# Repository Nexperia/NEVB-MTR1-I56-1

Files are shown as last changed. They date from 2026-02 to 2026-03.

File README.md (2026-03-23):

<picture align="center">
  <source media="(prefers-color-scheme: dark)" srcset="https://raw.githubusercontent.com/Nexperia/NEVB-MTR1-I56-1/refs/heads/main/images/nexperia_logo_white.svg">
  Nexperia Logo
</picture>

-----------------
# NEVB-MTR1-I56-1: 3-Phase Inverter Board Hardware Design Files

 

## Introduction

This repository contains the hardware design files for the NEVB-MTR1-I56-1 3-Phase Inverter Board, a key component of Nexperia's Motor Evaluation Kit NEVB-MTR1-KIT1. The inverter board serves as the main powerstage for driving the motor, interfacing with the Motor Controller Board.

The NEVB-MTR1-KIT1 evaluation kit includes:

- **Motor Controller Board (NEVB-MTR1-C-1)**: The central unit for motor control operations.
- **3-Phase Inverter Board (NEVB-MTR1-I56-1)**: The main powerstage for driving the motor (this repository).
- **Leonardo R3 Development Board**: Acts as the core microcontroller platform for the system.
- **3-Phase BLDC Motor with Hall Sensors**: The motor that is directly controlled by the system.
- Additional screws, plugs, and tools necessary for setup and operation.

## Board View

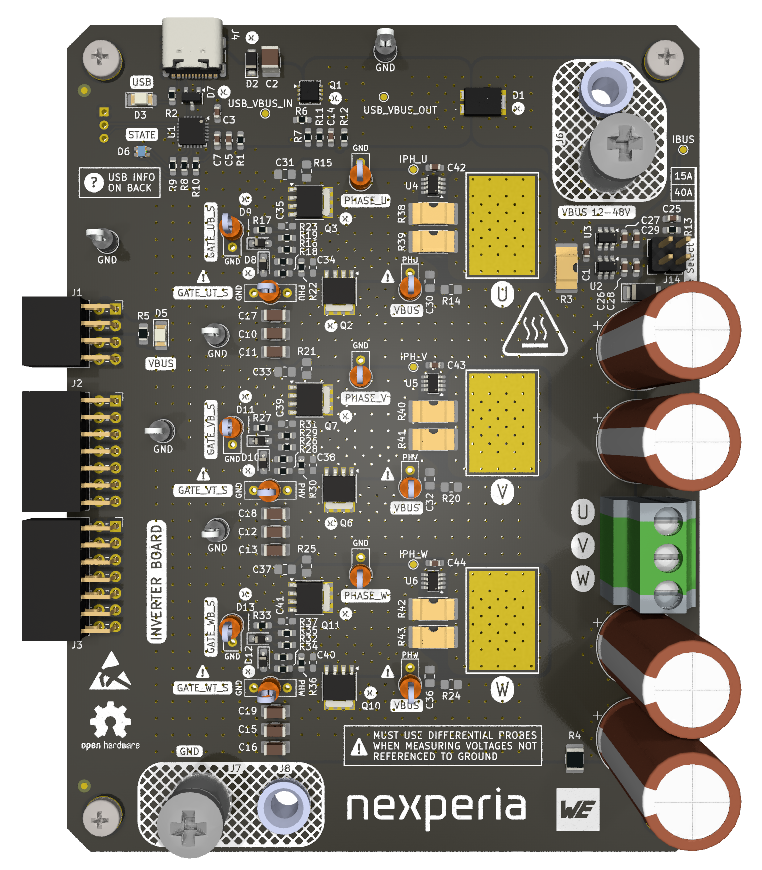
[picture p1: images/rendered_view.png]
Board Render


## Bill of Materials

An interactive Bill of Materials (iBOM) is available online at [https://nexperia.github.io/NEVB-MTR1-I56-1/ibom.html](https://nexperia.github.io/NEVB-MTR1-I56-1/ibom.html) or locally in the `bom/` directory (`bom/ibom.html`). The iBOM provides an interactive view of component placement, reference designators, and sourcing information. The BOM is also available in CSV format at `bom/nevb_mtr1_i56_1.csv`.

## Manufacturing Files

Gerber files for PCB manufacturing are located in the `gerbers/` directory.

## Design Software

This board was designed using [KiCad](https://www.kicad.org/) EDA software (version 9.0 or newer recommended).

To open and edit the design:

1. Install KiCad from [https://www.kicad.org/download/](https://www.kicad.org/download/)
2. Open the project file: `nevb_mtr1_i56_1.kicad_pro`

## Related Repositories

- **Firmware**: [NEVC-MTR1-t01](https://github.com/Nexperia/NEVC-MTR1-t01) - Trapezoidal control firmware for the evaluation kit
- **Motor Controller Board** [NEVB-MTR1-C-1](https://github.com/Nexperia/NEVB-MTR1-C-1) - Design files for the motor controller board

## Safety Precautions

When working with these hardware designs, exercise caution with high-voltage components and follow proper ESD, assembly, and testing procedures.

## Contributing

Contributions to improve the hardware design are welcome. To contribute:

- Fork the repository.
- Create a new branch for your feature or fix.
- Commit your changes with clear documentation.
- Push to your branch and submit a pull request.

## License

This project is licensed under the MIT/X Consortium License, a permissive free software license. For more details on the MIT/X Consortium License, please refer to the LICENSE file included in this repository.

## Schematics

The inverter board design is organized into hierarchical schematic sheets:

Main Schematic

Power Input

Input Current Sense

Capacitor Bank

Inverter

Phase Current Sense

Hardware and Notes

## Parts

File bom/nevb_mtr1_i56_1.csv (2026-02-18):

Reference | Value | Datasheet | Footprint | Qty | DNP | Manufacturer | Mfg Part No | Mouser Part No | RS Part No | Farnell Part No
C1 | 10n-100V | https://www.we-online.com/components/products/datasheet/885012206114.pdf | Capacitor_SMD:C_0603_1608Metric_Pad1.08x0.95mm_HandSolder | 1 |  | WURTH ELEKTRONIK | 885012206114 | 710-885012206114 | ~ | 2812368
C2 | 4.7u-25V | https://www.we-online.com/components/products/datasheet/885012209027.pdf | Capacitor_SMD:C_1210_3225Metric_Pad1.33x2.70mm_HandSolder | 1 |  | WURTH ELEKTRONIK | 885012209027 | 710-885012209027 | ~ | 4261488
C3,C14 | 0.1u-25V | https://www.we-online.com/components/products/datasheet/885012206071.pdf | Capacitor_SMD:C_0603_1608Metric_Pad1.08x0.95mm_HandSolder | 2 |  | WURTH ELEKTRONIK | 885012206071 | 710-885012206071 | ~ | 2495173
C4,C6,C8,C9 | 270u-100V | https://www.chemi-con.co.jp/products/relatedfiles/capacitor/catalog/KYBLL-e.PDF | Capacitor_THT:CP_Radial_D12.5mm_P5.00mm | 4 |  | CHEMI-CON | EKYB101ELL271MK30S | 661-EKYB101E271MK30S | ~ | ~
C5,C7 | 1u-6V3 | https://www.we-online.com/components/products/datasheet/885012206002.pdf | Capacitor_SMD:C_0603_1608Metric_Pad1.08x0.95mm_HandSolder | 2 |  | WURTH ELEKTRONIK | 885012206002 | 710-885012206002 | ~ | 2534013
C10,C11,C12,C13,C15,C16 | 4.7u-100V | https://search.murata.co.jp/Ceramy/image/img/A01X/G101/ENG/GRM31CZ72A475KE11-01A.pdf | Capacitor_SMD:C_1206_3216Metric_Pad1.33x1.80mm_HandSolder | 6 |  | MURATA | GRM31CZ72A475KE11L | 81-GRM31CZ72A475K11L | ~ | 4128569
C17,C18,C19 | 1u-100V | https://weblib.samsungsem.com/mlcc/mlcc-ec-data-sheet.do?partNumber=CL31B105KCHSNN | Capacitor_SMD:C_1206_3216Metric_Pad1.33x1.80mm_HandSolder | 3 |  | SAMSUNG ELECTRO-MECHANICS | CL31B105KCHSNNE | 187-CL31B105KCHSNNE | ~ | 4539191
C20,C21,C22,C23,C24 | NC | ~ | Capacitor_SMD:C_2220_5750Metric_Pad1.97x5.40mm_HandSolder | 5 | DNP | ~ | ~ | ~ | ~ | ~
C25 | 22p-16V | https://www.we-online.com/components/products/datasheet/885012006019.pdf | Capacitor_SMD:C_0603_1608Metric_Pad1.08x0.95mm_HandSolder | 1 |  | WURTH ELEKTRONIK | 885012006019 | 710-885012006019 | ~ | 2533830
C26,C27,C42,C43,C44 | 0.1u-16V | https://www.we-online.com/components/products/datasheet/885012206046.pdf | Capacitor_SMD:C_0603_1608Metric_Pad1.08x0.95mm_HandSolder | 5 |  | WURTH ELEKTRONIK | 885012206046 | 710-885012206046 | ~ | 2495170
C28,C29 | 2.2u-16V | https://www.we-online.com/components/products/datasheet/885012106029.pdf | Capacitor_SMD:C_0603_1608Metric_Pad1.08x0.95mm_HandSolder | 2 |  | WURTH ELEKTRONIK | 885012106029 | 710-885012106029 | ~ | 4061671
C30,C31,C32,C33,C36,C37 | NC | ~ | Capacitor_SMD:C_0805_2012Metric_Pad1.18x1.45mm_HandSolder | 6 | DNP | ~ | ~ | ~ | ~ | ~
C34,C35,C38,C39,C40,C41 | NC | ~ | Capacitor_SMD:C_0603_1608Metric_Pad1.08x0.95mm_HandSolder | 6 | DNP | ~ | ~ | ~ | ~ | ~
D1 | PMEG100V080ELPE | https://assets.nexperia.com/documents/data-sheet/PMEG100V080ELPE.pdf | project:CFP15B | 1 |  | NEXPERIA | PMEG100V080ELPEZ | 771-PMEG100V080ELPEZ | ~ | 3934785
D2 | PTVS20VS1UR | https://assets.nexperia.com/documents/data-sheet/PTVSXS1UR_SER.pdf | Diode_SMD:Nexperia_CFP3_SOD-123W | 1 |  | NEXPERIA | PTVS20VS1UR,115 | 771-PTVS20VS1UR115 | ~ | 1829244
D3 | USB | https://www.we-online.com/components/products/datasheet/150120GS75000.pdf | LED_SMD:LED_1206_3216Metric_Pad1.42x1.75mm_HandSolder | 1 |  | WURTH ELEKTRONIK | 150120GS75000 | 710-150120GS75000 | ~ | 2322085
D4 | PTVS60VP1UTP | https://assets.nexperia.com/documents/data-sheet/PTVSXP1UTP_SER.pdf | Diode_SMD:D_SOD-128 | 1 |  | NEXPERIA | PTVS60VP1UTP,115 | 771-PTVS60VP1UTP,115 | ~ | 3940904
D5 | VBUS | https://www.we-online.com/components/products/datasheet/150120GS75000.pdf | LED_SMD:LED_1206_3216Metric_Pad1.42x1.75mm_HandSolder | 1 |  | WURTH ELEKTRONIK | 150120GS75000 | 710-150120GS75000 | ~ | 2322085
D6 | PD STATE | https://www.we-online.com/components/products/datasheet/150066M153000.pdf | project:LED_Wurth_0606 | 1 |  | WURTH ELEKTRONIK | 150066M153000 | 710-150066M153000 | ~ | 2764964
D7 | PESD5V0L2UU | https://assets.nexperia.com/documents/data-sheet/PESD5V0L2UU_PESD6V0L2UU.pdf | Package_TO_SOT_SMD:SOT-23-3 | 1 |  | NEXPERIA | PESD5V0L2UU,115 | 771-PESD5V0L2UU115 | ~ | 2069363
D8,D9,D10,D11,D12,D13 | BAT760 | https://assets.nexperia.com/documents/data-sheet/BAT760.pdf | Diode_SMD:D_SOD-323_HandSoldering | 6 |  | NEXPERIA | BAT760,115 | 771-BAT760-T/R | ~ | 8734593
G1,G3,G7,G9,G13 | M5x6mm Screw | https://docs.rs-online.com/37dd/0900766b814985ee.pdf |  | 5 |  | RS PRO | 908-7693 | ~ | 908-7693 | ~
G2,G6,G8,G12 | M3x8mm Screw | https://docs.rs-online.com/c4c2/A700000009608830.pdf |  | 4 |  | RS PRO | 264-6436 | ~ | 264-6436 | ~
G4,G5,G10,G11 | M3x25mm F/F Standoff | https://www.we-online.com/components/products/datasheet/970250321.pdf |  | 4 |  | WURTH ELEKTRONIK | 970250321 | 710-970250321 | ~ | 2884579
G14 | 2.54mm Jumper | https://cdn.harwin.com/pdfs/M7684-M7687.pdf |  | 1 |  | HARWIN | M7685-05 | 855-M7685-05 | ~ | 3218478
J1 | VIN | https://www.we-online.com/components/products/datasheet/613008243121.pdf | project:PinSocket_2x04_P2.54mm_Horizontal_Clipped_SilkScreen | 1 |  | WURTH ELEKTRONIK | 613008243121 | 710-613008243121 | ~ | 2827954
J2 | Signals1 | https://www.we-online.com/components/products/datasheet/613014243121.pdf | project:PinSocket_2x07_P2.54mm_Horizontal_Clipped_SilkScreen | 1 |  | WURTH ELEKTRONIK | 613014243121 | ~ | ~ | 2827957
J3 | Signals2 | https://www.we-online.com/components/products/datasheet/613014243121.pdf | project:PinSocket_2x07_P2.54mm_Horizontal_Clipped_SilkScreen | 1 |  | WURTH ELEKTRONIK | 613014243121 | ~ | ~ | 2827957
J4 | USB4215-03-A | https://www.we-online.com/components/products/datasheet/629722000214.pdf | project:USB_C_Receptacle_GCT_USB4105-xx-A_16P_TopMnt_Horizontal | 1 |  | WURTH ELEKTRONIK | 629722000214 | 710-629722000214 | ~ | 4146212
J5 | VBUS | https://www.keyelco.com/product-pdf.cfm?p=2379 | project:MountingHole_Keystone_575-4 | 1 |  | KEYSTONE ELECTRONICS | 575-4 | 534-575-4 | ~ | 3366825
J6 | VBUS | https://www.we-online.com/components/products/datasheet/7466205R.pdf | project:Terminal_Wuerth_7466205R_Custom1 | 1 |  | WURTH ELEKTRONIK | 7466205R | 710-7466205R | ~ | 2748965
J7 | GND | https://www.we-online.com/components/products/datasheet/7466205R.pdf | project:Terminal_Wuerth_7466205R_Custom1 | 1 |  | WURTH ELEKTRONIK | 7466205R | 710-7466205R | ~ | 2748965
J8 | GND | https://www.keyelco.com/product-pdf.cfm?p=2379 | project:MountingHole_Keystone_575-4 | 1 |  | KEYSTONE ELECTRONICS | 575-4 | 534-575-4 | ~ | 3366825
J9 | MOTOR | https://www.we-online.com/components/products/datasheet/691253710002.pdf | project:TerminalBlock_Wurth_69125x710003 | 1 |  | WURTH ELEKTRONIK | 691253710003 | 710-691253710003 | ~ | 3767705
J10 | PHASE_U | https://www.we-online.com/components/products/datasheet/7466205R.pdf | project:Terminal_Wuerth_7466205R_Custom2 | 1 |  | WURTH ELEKTRONIK | 7466205R | 710-7466205R | ~ | 2748965
J11 | PHASE_V | https://www.we-online.com/components/products/datasheet/7466205R.pdf | project:Terminal_Wuerth_7466205R_Custom2 | 1 |  | WURTH ELEKTRONIK | 7466205R | 710-7466205R | ~ | 2748965
J12 | PHASE_W | https://www.we-online.com/components/products/datasheet/7466205R.pdf | project:Terminal_Wuerth_7466205R_Custom2 | 1 |  | WURTH ELEKTRONIK | 7466205R | 710-7466205R | ~ | 2748965
J13 | I2C | https://www.we-online.com/components/products/datasheet/62000311121.pdf | Connector_PinHeader_2.00mm:PinHeader_1x03_P2.00mm_Vertical | 1 | DNP | WURTH ELEKTRONIK | 62000311121 | 710-62000311121 | ~ | 3583827
J14 | IBUS GAIN SEL | https://www.we-online.com/components/products/datasheet/61300421121.pdf | Connector_PinHeader_2.54mm:PinHeader_2x02_P2.54mm_Vertical | 1 |  | WURTH ELEKTRONIK | 61300421121 | 710-61300421121 | ~ | 2356130
Q1 | PXP6R1-30QL | https://assets.nexperia.com/documents/data-sheet/PXP6R1-30QL.pdf | project:MLPAK33 | 1 |  | NEXPERIA | PXP6R1-30QLJ | 771-PXP6R1-30QLJ | ~ | 3868932
Q2,Q3,Q6,Q7,Q10,Q11 | PSMN3R9-100YSF | https://assets.nexperia.com/documents/data-sheet/PSMN3R9-100YSF.pdf | project:LFPAK56 | 6 |  | NEXPERIA | PSMN3R9-100YSFX | 771-PSMN3R9-100YSFX | ~ | 3268030
Q4,Q5,Q8,Q9,Q12,Q13 | PSMN3R9-100YSF | https://assets.nexperia.com/documents/data-sheet/PSMN3R9-100YSF.pdf | project:LFPAK56 | 6 | DNP | NEXPERIA | PSMN3R9-100YSFX | 771-PSMN3R9-100YSFX | ~ | 3268030
R1,R12 | 1K | https://www.kamaya.co.jp/upload/products_pdf/kamaya_products(RMC1-32,RMC1-20,RMC1-16S,RMC1-16,RMC1-10,RMC1-8,RMC1-4,RMC1-2,RMC1)_english_20240824_132441.pdf | Resistor_SMD:R_0603_1608Metric_Pad0.98x0.95mm_HandSolder | 2 |  | KAMAYA | RMC1/16-102JTP | 791-RMC1/16-102JTP | ~ | ~
R2,R6 | 100K | https://www.yageo.com/upload/media/product/app/datasheet/rchip/pyu-rt_1-to-0.01_rohs_l.pdf | Resistor_SMD:R_0603_1608Metric_Pad0.98x0.95mm_HandSolder | 2 |  | YAGEO | RT0603FRE07100KL | 603-RT0603FRE07100KL | ~ | 1500586
R3 | 4m-1%-4W | https://www.yageo.com/upload/media/product/app/datasheet/rchip/pyu-pu_51_rohs_l.pdf | project:R_2512_6332Metric_Pad1.40x3.35mm_HandSolder | 1 |  | YAGEO | PU2512FKM130R004L | 603-PU2512FKM130R04L | ~ | 4067467
R4 | 10K | https://www.yageo.com/upload/media/product/products/datasheet/rchip/PYu-RC_Group_51_RoHS_L_12.pdf | Resistor_SMD:R_1210_3225Metric_Pad1.30x2.65mm_HandSolder | 1 |  | YAGEO | RC1210JR-0710KL | 603-RC1210JR-0710KL | ~ | 3496383
R5 | 100K | https://www.kamaya.co.jp/upload/products_pdf/kamaya_products(RMC1-32,RMC1-20,RMC1-16S,RMC1-16,RMC1-10,RMC1-8,RMC1-4,RMC1-2,RMC1)_english_20240824_132441.pdf | Resistor_SMD:R_0805_2012Metric_Pad1.20x1.40mm_HandSolder | 1 |  | KAMAYA | RMC1/10K1003FTP | 791-RMC1/10K1003FTP | ~ | ~
R7,R8,R9,R10 | 22K | https://www.kamaya.co.jp/upload/products_pdf/kamaya_products(RMC1-32,RMC1-20,RMC1-16S,RMC1-16,RMC1-10,RMC1-8,RMC1-4,RMC1-2,RMC1)_english_20240824_132441.pdf | Resistor_SMD:R_0603_1608Metric_Pad0.98x0.95mm_HandSolder | 4 |  | KAMAYA | RMC1/16K2202FTP | 791-RMC1/16K2202FTP | ~ | ~
R11 | 100 | https://www.bourns.com/docs/product-datasheets/cr.pdf | Resistor_SMD:R_0603_1608Metric_Pad0.98x0.95mm_HandSolder | 1 |  | BOURNS | CR0603-FX-1000ELF | 652-CR0603FX-1000ELF | ~ | 2008332
R13 | 20K | https://www.bourns.com/docs/product-datasheets/cr.pdf | Resistor_SMD:R_0603_1608Metric_Pad0.98x0.95mm_HandSolder | 1 |  | BOURNS | CR0603-FX-2002ELF | 652-CR0603FX-2002ELF | ~ | 2333523
R14,R15,R20,R21,R24,R25 | NC | ~ | Resistor_SMD:R_0805_2012Metric_Pad1.20x1.40mm_HandSolder | 6 | DNP | ~ | ~ | ~ | ~ | ~
R16,R17,R26,R27,R32,R33 | 4R7 | https://www.kamaya.co.jp/upload/products_pdf/kamaya_products(RMC10,RMC16,RMC20,RMC32,RMC35)_english_20190102_164618.pdf | Resistor_SMD:R_0603_1608Metric_Pad0.98x0.95mm_HandSolder | 6 |  | KAMAYA | RMC16-4R7FTP | 791-RMC16-4R7FTP | ~ | ~
R18,R19,R28,R29,R34,R35 | 10 | https://www.kamaya.co.jp/upload/products_pdf/kamaya_products(RMC1-32,RMC1-20,RMC1-16S,RMC1-16,RMC1-10,RMC1-8,RMC1-4,RMC1-2,RMC1)_english_20240824_132441.pdf | Resistor_SMD:R_0603_1608Metric_Pad0.98x0.95mm_HandSolder | 6 |  | KAMAYA | RMC1/16K10R0FTP | 791-RMC1/16K10R0FTP | ~ | ~
R22,R23,R30,R31,R36,R37 | 10K | https://www.kamaya.co.jp/upload/products_pdf/kamaya_products(RMC1-32,RMC1-20,RMC1-16S,RMC1-16,RMC1-10,RMC1-8,RMC1-4,RMC1-2,RMC1)_english_20240824_132441.pdf | Resistor_SMD:R_0603_1608Metric_Pad0.98x0.95mm_HandSolder | 6 |  | KAMAYA | RMC1/16-103JTP | 791-RMC1/16103JTP | ~ | ~
R38,R39,R40,R41,R42,R43 | 5m-1%-4W | https://www.yageo.com/upload/media/product/app/datasheet/rchip/pyu-pu_51_rohs_l.pdf | project:R_2512_6332Metric_Pad1.40x3.35mm_HandSolder | 6 |  | YAGEO | PU2512FKM130R005L | 603-PU2512FKM130R05L | ~ | ~
TP1,TP2,TP3,TP4,TP5 | GND | https://www.keyelco.com/product-pdf.cfm?p=14635 | project:TestPoint_THTPad_D3.0mm_Drill1.5mm | 5 |  | KEYSTONE ELECTRONICS | 5288 | 534-5288 | ~ | ~
TP11 | GATE_UT_S | https://www.keyelco.com/product-pdf.cfm?p=1322 | project:TestPoint_3Pads_Pitch2.54mm_Drill1.5mm | 1 |  | KEYSTONE ELECTRONICS | 5013 | 534-5013 | ~ | 2301289
TP12 | PHASE_U | https://www.keyelco.com/product-pdf.cfm?p=1322 | project:TestPoint_2Pads_Pitch2.54mm_Drill1.5mm | 1 |  | KEYSTONE ELECTRONICS | 5013 | 534-5013 | ~ | 2301289
TP13 | GATE_UB_S | https://www.keyelco.com/product-pdf.cfm?p=1322 | project:TestPoint_2Pads_Pitch2.54mm_Drill1.5mm | 1 |  | KEYSTONE ELECTRONICS | 5013 | 534-5013 | ~ | 2301289
TP14,TP18,TP22 | VBUS | https://www.keyelco.com/product-pdf.cfm?p=1322 | project:TestPoint_2Pads_Pitch2.54mm_Drill1.5mm | 3 |  | KEYSTONE ELECTRONICS | 5013 | 534-5013 | ~ | 2301289
TP15 | GATE_VT_S | https://www.keyelco.com/product-pdf.cfm?p=1322 | project:TestPoint_3Pads_Pitch2.54mm_Drill1.5mm | 1 |  | KEYSTONE ELECTRONICS | 5013 | 534-5013 | ~ | 2301289
TP16 | PHASE_V | https://www.keyelco.com/product-pdf.cfm?p=1322 | project:TestPoint_2Pads_Pitch2.54mm_Drill1.5mm | 1 |  | KEYSTONE ELECTRONICS | 5013 | 534-5013 | ~ | 2301289
TP17 | GATE_VB_S | https://www.keyelco.com/product-pdf.cfm?p=1322 | project:TestPoint_2Pads_Pitch2.54mm_Drill1.5mm | 1 |  | KEYSTONE ELECTRONICS | 5013 | 534-5013 | ~ | 2301289
TP19 | GATE_WT_S | https://www.keyelco.com/product-pdf.cfm?p=1322 | project:TestPoint_3Pads_Pitch2.54mm_Drill1.5mm | 1 |  | KEYSTONE ELECTRONICS | 5013 | 534-5013 | ~ | 2301289
TP20 | PHASE_W | https://www.keyelco.com/product-pdf.cfm?p=1322 | project:TestPoint_2Pads_Pitch2.54mm_Drill1.5mm | 1 |  | KEYSTONE ELECTRONICS | 5013 | 534-5013 | ~ | 2301289
TP21 | GATE_WB_S | https://www.keyelco.com/product-pdf.cfm?p=1322 | project:TestPoint_2Pads_Pitch2.54mm_Drill1.5mm | 1 |  | KEYSTONE ELECTRONICS | 5013 | 534-5013 | ~ | 2301289
U1 | STUSB4500QTR | https://www.st.com/resource/en/datasheet/stusb4500.pdf | project:QFN-24-1EP_4x4mm_P0.5mm_EP2.7x2.7mm | 1 |  | STMICROELECTRONICS | STUSB4500QTR | 511-STUSB4500QTR | ~ | 2980889
U2 | MCP6C02T-020 | https://ww1.microchip.com/downloads/aemDocuments/documents/OTH/ProductDocuments/DataSheets/Zero-Drift-65V-High-Side-Current-Sense-Amplifier-DS20006129C.pdf | Package_TO_SOT_SMD:SOT-23-6 | 1 |  | MICROCHIP TECHNOLOGY | MCP6C02T-020E/CHY | 579-MCP6C02T020ECHY | ~ | 2984042
U3 | MCP6C02T-050 | https://ww1.microchip.com/downloads/aemDocuments/documents/OTH/ProductDocuments/DataSheets/Zero-Drift-65V-High-Side-Current-Sense-Amplifier-DS20006129C.pdf | Package_TO_SOT_SMD:SOT-23-6 | 1 |  | MICROCHIP TECHNOLOGY | MCP6C02T-050E/CHY | 579-MCP6C02T050ECHY | ~ | 2984043
U4,U5,U6 | INA241A2xDDF | https://www.ti.com/lit/ds/symlink/ina241b.pdf | project:SOT-23-8 | 3 |  | TEXAS INSTRUMENTS | INA241A2IDDFR | 595-INA241A2IDDFR | ~ | ~
